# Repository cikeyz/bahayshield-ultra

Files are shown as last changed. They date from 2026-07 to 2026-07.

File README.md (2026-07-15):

# BahayShield ULTRA

<p align="center">
  <strong>Offline flood and typhoon preparedness controller for a tabletop home-safety demo.</strong><br>
  Arduino Mega 2560 Pro · HC-SR04 · BME280 · TRI scoring · low-voltage relay cut
</p>

<p align="center">
  <a href="#overview">Overview</a>
  &nbsp;·&nbsp;
  <a href="#features">Features</a>
  &nbsp;·&nbsp;
  <a href="#gallery">Gallery</a>
  &nbsp;·&nbsp;
  <a href="#quick-start">Quick Start</a>
  &nbsp;·&nbsp;
  <a href="#project-structure">Structure</a>
  &nbsp;·&nbsp;
  <a href="#license">License</a>
</p>

<p align="center">
  
  
  
  
  
  
</p>

## Contents

- [Overview](#overview)
- [Features](#features)
- [System architecture](#system-architecture)
- [Hardware](#hardware)
- [Firmware](#firmware)
- [Gallery](#gallery)
- [Quick Start](#quick-start)
- [Project Structure](#project-structure)
- [Safety](#safety)
- [License](#license)
- [Course Note](#course-note)

## Overview

BahayShield ULTRA is an offline microcontroller system that combines ultrasonic water-level sensing with barometric pressure trend analysis. It computes a Typhoon Risk Index (TRI), stages visual and audible alerts, and can open a low-voltage demo load through a relay when risk stays high long enough.

The demo unit pairs a control enclosure with a house diorama and clear flood tray. It is a tabletop simulation, not a field-installed household electrical product, and it does not switch AC mains.

**Controller:** final build uses an **Arduino Mega 2560 Pro** compact module (ATmega2560, CH340 USB, dual-row 100-mil headers). Early breadboard work may use a full-size Mega 2560 form factor; the MCU and IDE board target stay the same (`Arduino Mega or Mega 2560`).

## Features

| Feature | Description |
|---|---|
| Water level | HC-SR04 over a fixed mast; mapped to dry / ankle / knee / waist / critical |
| Barometric trend | BME280 pressure feeds rolling slope and baseline into TRI |
| Storm profiles | Habagat, Bagyo, and Flash Flood reweight water vs pressure |
| Staged alerts | LED bar, alert LED, buzzer cadence, 20x4 LCD |
| Relay cut | Relay 1 COM-NC on a 5 V demo load; active-LOW coil drive |
| Operator inputs | PCF8574 4x4 keypad, A1 button ladder, serial commands |
| Event log | DS3231 timebase + AT24C32 EEPROM with checksummed records |
| Mechanical stack | KiCad motherboard project, 3D-printed enclosure, HC-SR04 mast |

## System architecture

```mermaid
flowchart LR
  subgraph Inputs
    US[HC-SR04]
    BME[BME280]
    POT[A0 pressure pot]
    BTN[Buttons]
    KEY[Keypad]
  end

  subgraph Controller
    MCU[Mega 2560 Pro<br/>ATmega2560<br/>TRI + FSM]
    RTC[DS3231 RTC]
    PWR[XL4015 5 V rail]
  end

  subgraph Outputs
    LED[TRI LEDs + alert]
    BUZ[Active buzzer]
    REL[Relay 1 COM-NC<br/>5 V load]
    LCD[20x4 I2C LCD]
    LOG[AT24C32 event log]
  end

  US --> MCU
  BME --> MCU
  POT --> MCU
  BTN --> MCU
  KEY --> MCU
  RTC --> MCU
  PWR --> MCU
  MCU --> LED
  MCU --> BUZ
  MCU --> REL
  MCU --> LCD
  MCU --> LOG
```

Editable diagrams: [`docs/diagrams/`](docs/diagrams/).  
Deeper write-up: [`docs/overview.md`](docs/overview.md).

## Hardware

| Block | Part | Role |
|---|---|---|
| MCU | Arduino Mega 2560 Pro (ATmega2560) | Final controller; 5 V on `5V` pin (`VIN` unused) |
| Water | HC-SR04 | Distance over diorama tray |
| Environment | BME280 (I2C, typically `0x76`) | Pressure for TRI; temp/humidity for display only |
| RTC + log | DS3231 + AT24C32 | Timekeeping and event log |
| Display | 20x4 I2C LCD (primary `0x27`) | TRI, profile, water, pressure, state |
| Keypad | 4x4 via PCF8574 (`0x20`) | Profile, mute, cut, ack, page |
| Buttons | 3x tactile on A1 ladder | Yellow cut, Blue view, Green ack |
| Indicators | 5 TRI LEDs + alert LED + buzzer | Staged alert UI |
| Actuator | 2-ch 5 V relay module | Relay 1 demo-load cut; Relay 2 spare |
| Power | USB-C PD source → XL4015 buck → 5.00 V | Fuse + reverse protection on the design |
| Load | 5 V LED strip on Relay 1 COM-NC | Stand-in for a ground-floor branch |
| PCB | KiCad Rev A motherboard | Headers for Mega 2560 Pro and modules |
| Enclosure | Printed base, top panel, BME280 cage, mast | Control unit + sensor geometry |

- Pin map: [`hardware/pinout.md`](hardware/pinout.md)
- Power path: [`hardware/power-tree.md`](hardware/power-tree.md)
- BOM: [`hardware/bom.md`](hardware/bom.md)
- Wiring: [`hardware/wiring-overview.md`](hardware/wiring-overview.md)
- PCB project: [`pcb/`](pcb/)
- Enclosure STLs: [`enclosure/`](enclosure/)

## Firmware

Production sketch: [`firmware/bahayshield-ultra/`](firmware/bahayshield-ultra/)

- Non-blocking `millis()` scheduler
- Fixed-point TRI suited to Mega-class SRAM
- Non-blocking HC-SR04 echo state machine
- Active-LOW relay with confirm window before power-cut latch
- Serial at `115200` baud

Bring-up suite: [`firmware/bring-up/`](firmware/bring-up/) (I2C, LCD, keypad, RTC, BME280, relay, ultrasonic, full breadboard integration).

Libraries for production:

```text
Wire
Adafruit BME280
Adafruit Unified Sensor
Adafruit BusIO
```

LCD and PCF8574 keypad use direct `Wire` access.

## Gallery

| Mega 2560 Pro (front) | Mega 2560 Pro (back) |
|---|---|
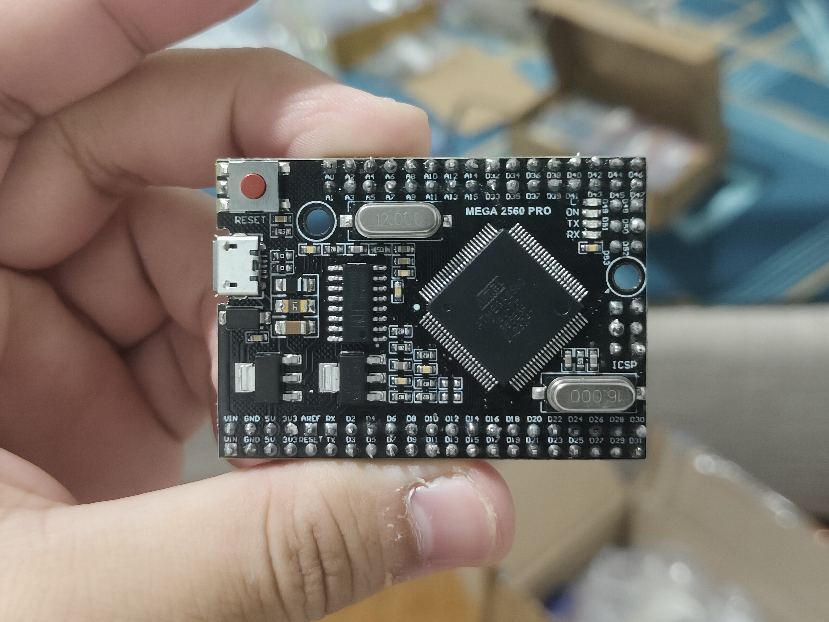
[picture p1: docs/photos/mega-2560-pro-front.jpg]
Mega 2560 Pro front
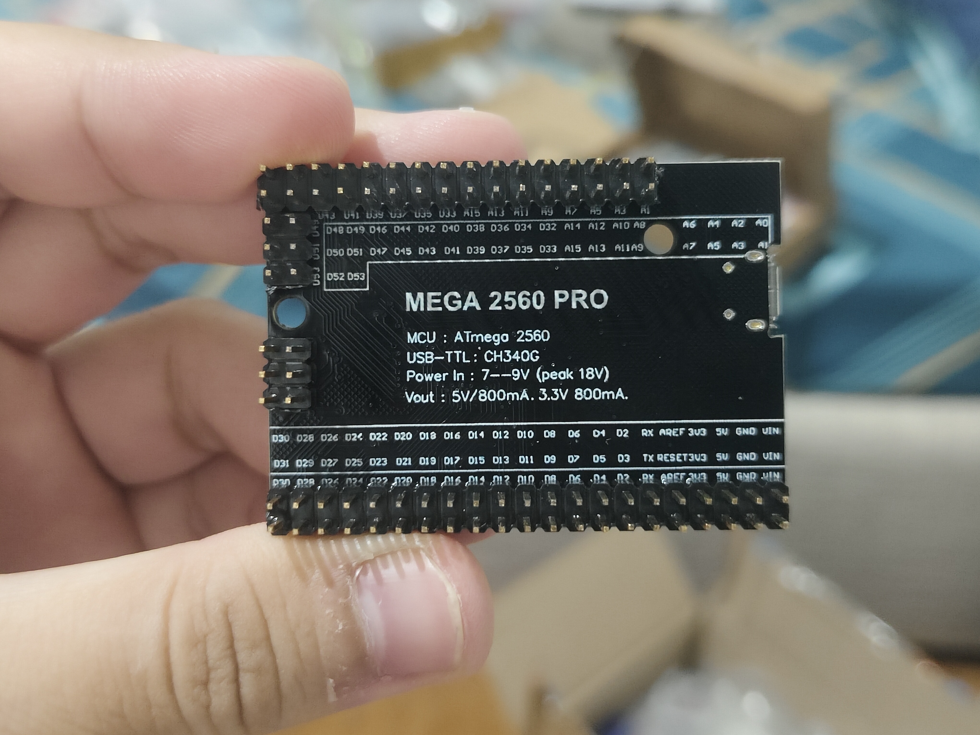
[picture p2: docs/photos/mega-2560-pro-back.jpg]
Mega 2560 Pro back
|  |  |

| BME280 | DS3231 + AT24C32 | XL4015 buck |
|---|---|---|
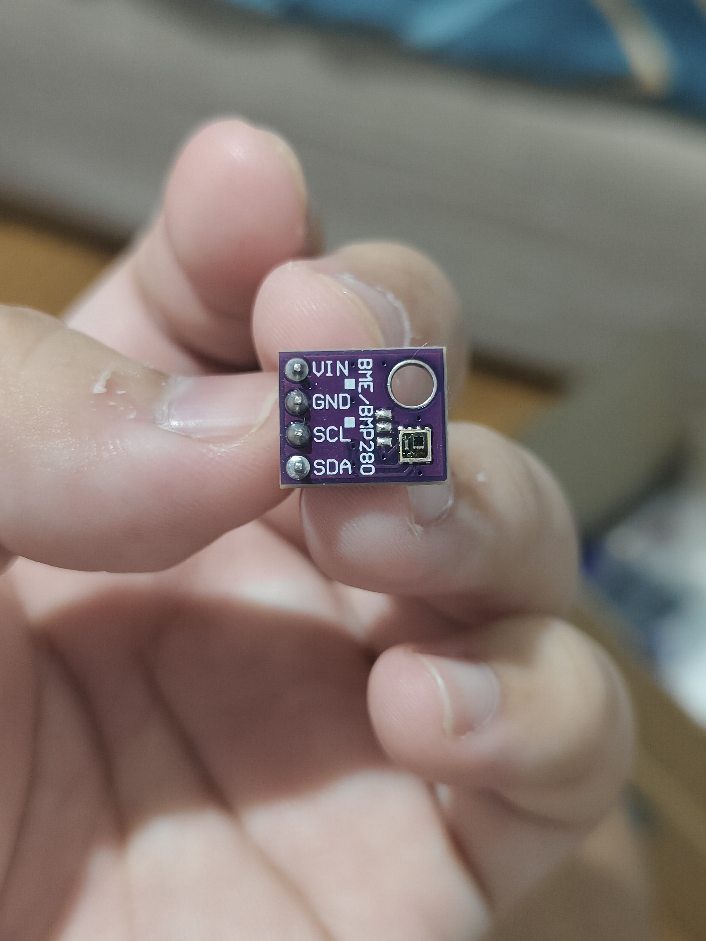
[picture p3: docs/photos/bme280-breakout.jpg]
BME280
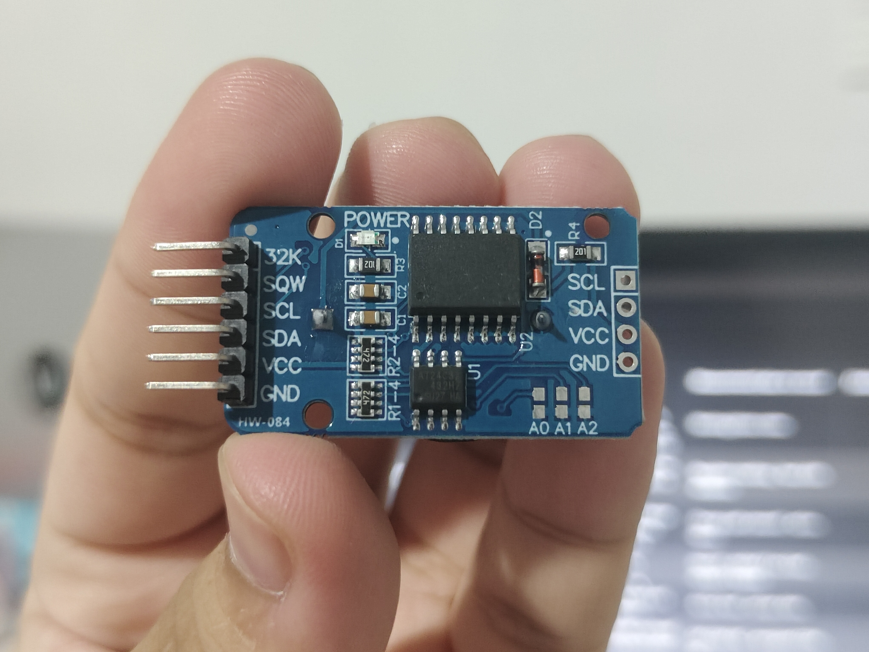
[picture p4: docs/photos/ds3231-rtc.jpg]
DS3231
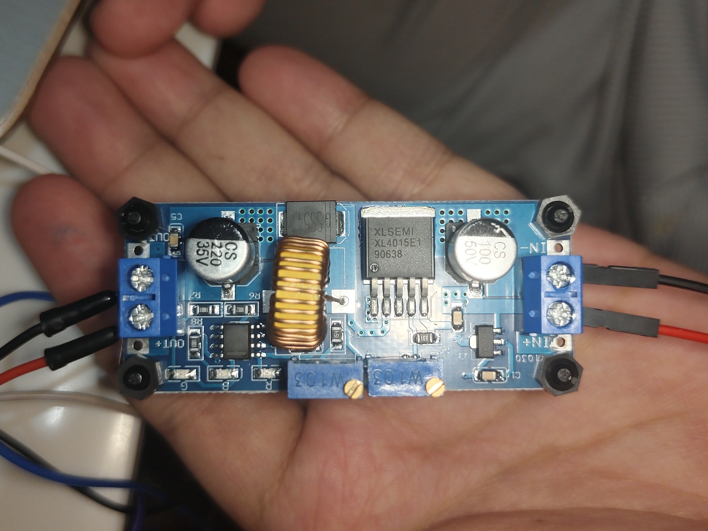
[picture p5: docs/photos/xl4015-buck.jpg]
XL4015
|  |  |  |

| Serial: upload OK | Serial: HC-SR04 |
|---|---|
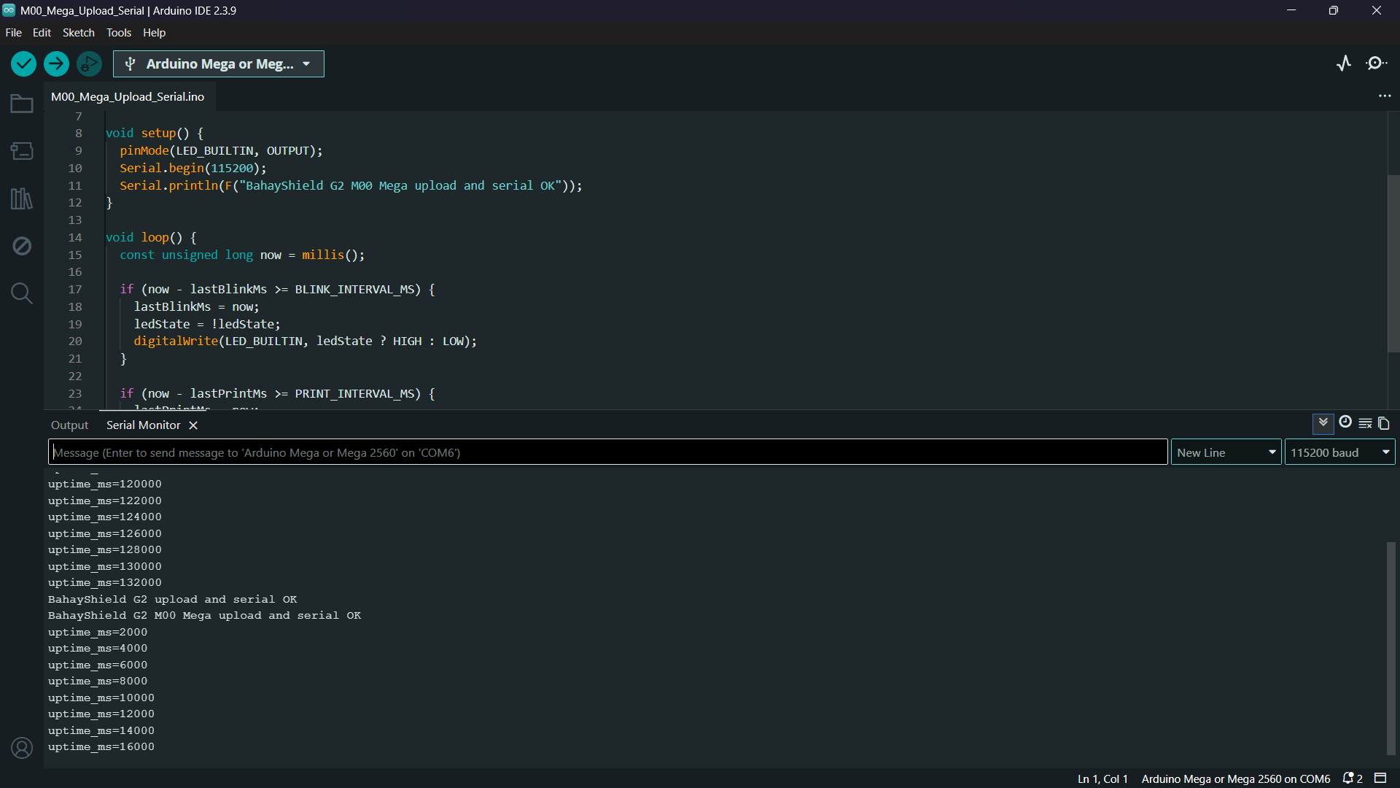
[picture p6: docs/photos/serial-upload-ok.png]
Upload OK
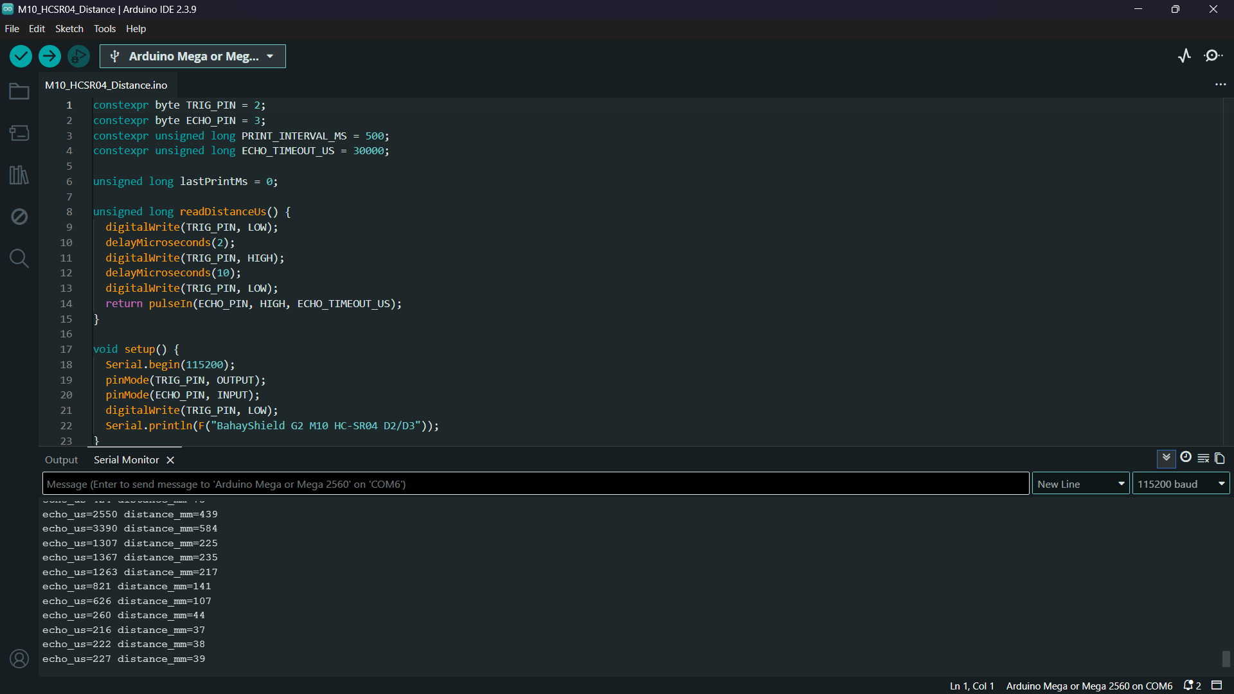
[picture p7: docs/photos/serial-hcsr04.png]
HC-SR04
|  |  |

| Serial: keypad | Serial: LCD I2C |
|---|---|
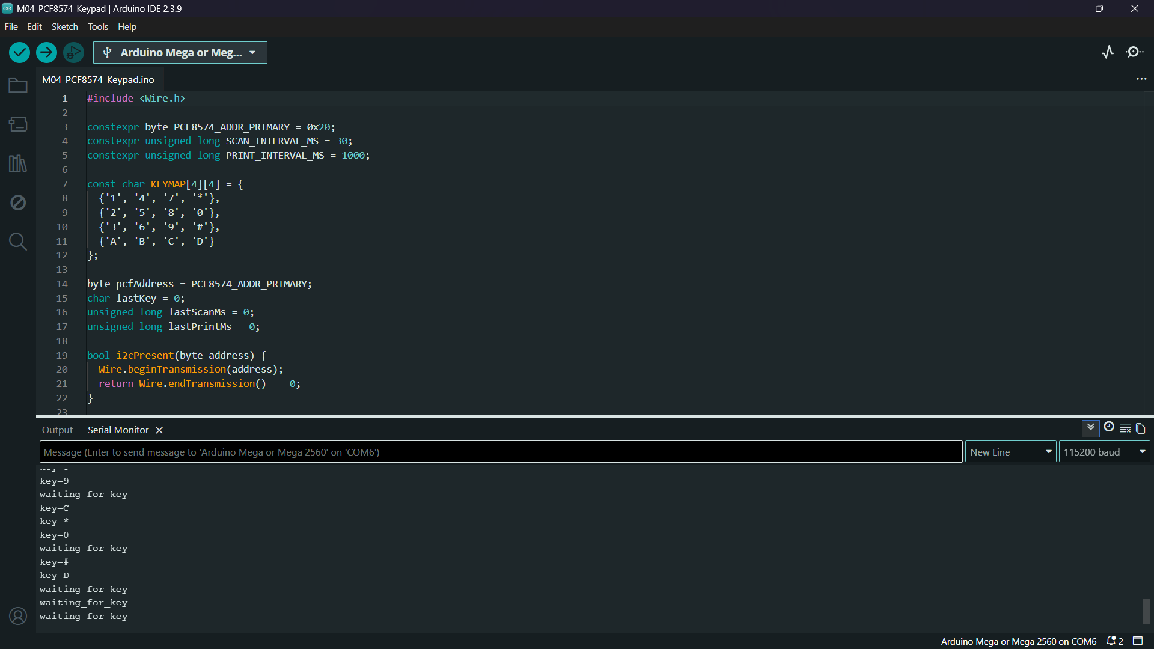
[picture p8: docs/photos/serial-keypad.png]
Keypad
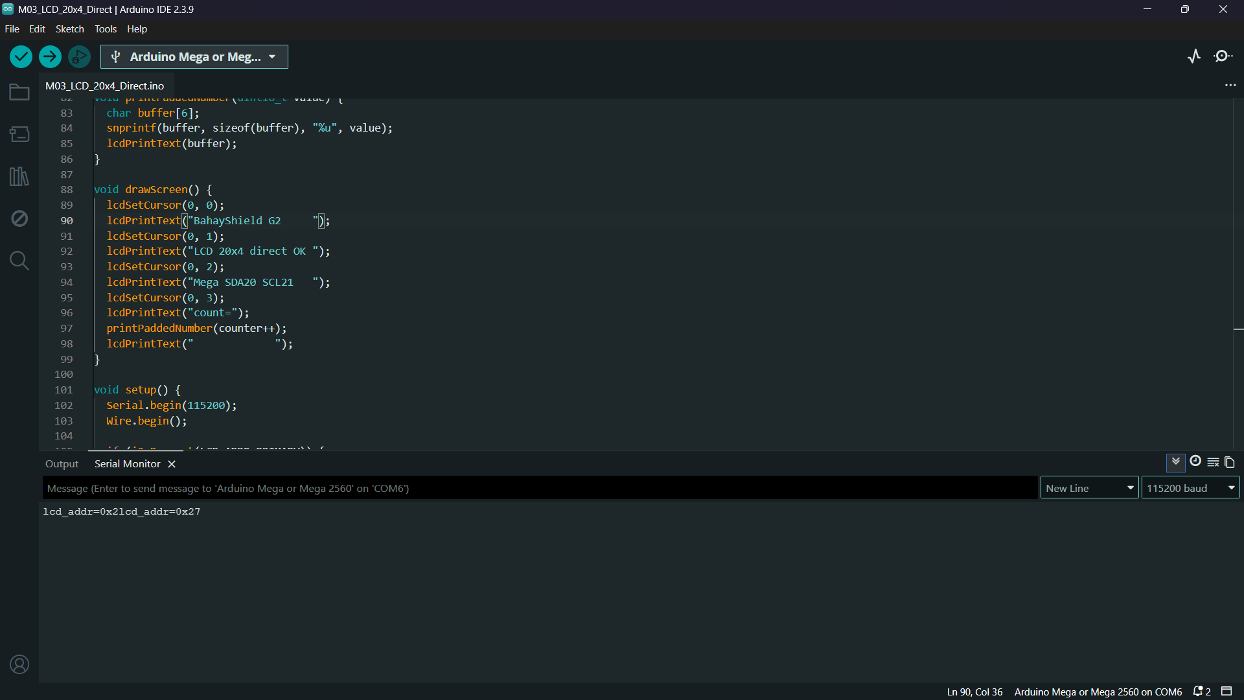
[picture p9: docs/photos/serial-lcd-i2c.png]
LCD
|  |  |

Full set: [`docs/photos/`](docs/photos/).

## Quick Start

```bash
git clone https://github.com/cikeyz/bahayshield-ultra.git
cd bahayshield-ultra
```

1. Install Arduino IDE or Arduino CLI.
2. Select board **Arduino Mega or Mega 2560** (ATmega2560 on the Mega 2560 Pro module).
3. Install Adafruit BME280 and its dependencies.
4. Open `firmware/bahayshield-ultra/bahayshield-ultra.ino`.
5. Upload with the external load disconnected.
6. Open Serial Monitor at `115200`. Confirm I2C devices, LCD, and inactive relay before connecting the LED-strip load path.

| Cmd | Action |
|-----|---|
| `c` | Manual relay cut |
| `a` | Acknowledge / reset when safe |
| `v` | Cycle LCD page |
| `m` | Mute buzzer |
| `1` / `2` / `3` | Habagat / Bagyo / Flash Flood |
| `?` | Help |

Demo script: [`docs/demo-procedure.md`](docs/demo-procedure.md).

## Project Structure

```text
bahayshield-ultra/
├── README.md
├── LICENSE
├── .gitignore
├── firmware/
│   ├── bahayshield-ultra/     # production sketch
│   └── bring-up/              # M00-M16 driver tests
├── hardware/
│   ├── pinout.md
│   ├── power-tree.md
│   ├── bom.md
│   └── wiring-overview.md
├── pcb/
│   ├── README.md
│   ├── rev-a/                 # KiCad Rev A + local libraries
│   └── archive/prototype-1/   # early routing baseline
├── enclosure/
│   ├── README.md
│   ├── scad/
│   └── stl/
└── docs/
    ├── overview.md
    ├── demo-procedure.md
    ├── diagrams/
    └── photos/
```

## Safety

- Relay contacts switch a **5 V demo load** only. No AC, outlets, extension cords, or household branch wiring.
- Humidity and temperature are display/log context. Pressure is the barometric input to TRI and cutoff logic.
- Storm demos can use the A0 potentiometer for a repeatable pressure curve while BME280 still reports real ambient pressure.
- Verify buck output at 5.00 V, relay active level, and COM-NC continuity before a live demo.

## License

MIT. See [LICENSE](LICENSE).

## Course Note

Built for CMPE 311 (Microprocessor Systems), Polytechnic University of the Philippines, Group 4, A.Y. 2025-2026, under Engr. Rufo I. Marasigan Jr., D.Eng, PCpE. Published here as a standalone project.

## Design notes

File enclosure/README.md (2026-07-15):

# Enclosure and mast

Printed parts for the control unit and HC-SR04 mast. Sized around the **Mega 2560 Pro** motherboard stack, internal relay/buck bays, and a top-panel BME280 vent cage open to room air.

## STL set

| File | Role |
|---|---|
| `stl/bahayshield-base-tray.stl` | Base tray |
| `stl/bahayshield-top-panel.stl` | Top panel |
| `stl/bme280-vent-cage.stl` | Room-air sensor cage |
| `stl/hcsr04-faceplate.stl` | Sensor faceplate |
| `stl/hcsr04-mast-base.stl` | Mast base |
| `stl/hcsr04-mast-upright-132mm.stl` | Upright |
| `stl/hcsr04-mast-arm.stl` | Arm |

Editable source: `scad/bahayshield-enclosure.scad` and `scad/generate_enclosure_stl.py`.

## Print notes

| Setting | Suggestion |
|---|---|
| Material | PETG preferred; PLA+ OK for fit checks |
| Layer height | 0.20 mm final |
| Walls | 4+ |
| Infill | ~25% |
| Order | Faceplate and BME280 cage first, then top panel and base, then mast |

Expect holes to need light reaming after print. Keep BME280 exposed to room air.

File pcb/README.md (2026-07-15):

# PCB

## Rev A

Path: [`rev-a/`](rev-a/)

KiCad motherboard for BahayShield ULTRA. It sockets an **Arduino Mega 2560 Pro** on 100-mil headers and brings out I2C modules, relay logic, load path, indicators, and power protection.

```text
pcb/rev-a/BahayShield-ULTRA-RevA-Manual.kicad_pro
```

Local symbol and footprint libraries: `rev-a/libraries/`.

### Status

- Schematic covers the intended nets: MCU headers, I2C, relay inputs, load terminals, protection, bulk caps, TRI LEDs, buzzer drive.
- Before ordering boards, re-run ERC/DRC on your KiCad version, confirm relay header order (`GND IN1 IN2 VCC`) and contact group (`NO COM NC`) against the module you hold, and check keep-outs against the printed enclosure.
- This tree is a design package, not a certified production Gerber drop.

## Prototype-1 (archive)

Path: [`archive/prototype-1/`](archive/prototype-1/)

Early low-voltage routing baseline. Kept for history. Prefer Rev A for current pin and feature set.

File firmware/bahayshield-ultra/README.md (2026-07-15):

# Production firmware

Board: **Arduino Mega 2560 Pro** (ATmega2560, 5 V).

Arduino IDE: **Arduino Mega or Mega 2560**.

## Folder

```text
firmware/bahayshield-ultra/
├── bahayshield-ultra.ino
├── config.h
├── pins.h
├── event_log.h
└── event_log.cpp
```

## Libraries

```text
Wire
Adafruit BME280
Adafruit Unified Sensor
Adafruit BusIO
```

## Serial

Baud: `115200`.

| Command | Action |
|---|---|
| `c` | Manual relay cut |
| `a` | Acknowledge / reset when safe |
| `v` | Cycle LCD page |
| `m` | Mute buzzer |
| `1` / `2` / `3` | Habagat / Bagyo / Flash Flood |
| `e` | Write one event-log smoke record |
| `?` | Help |

Upload with the external load disconnected. Confirm startup prints, LCD, I2C, inactive relay, and 5.00 V rails before connecting the LED-strip load path.

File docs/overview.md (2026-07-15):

# System overview

## Problem

During typhoons and monsoon floods, homes often lose connectivity first. Water and energized ground-floor wiring raise electrocution risk. BahayShield ULTRA is an offline controller that estimates rising risk from water level and pressure trend, stages alerts, and opens a safe low-voltage demo load.

## Architecture

1. **Sense** - HC-SR04 water height, BME280 pressure, A0 pressure simulator for repeatable demos, RTC timebase.
2. **Decide** - Profile-weighted TRI with hysteresis; confirm window before latching power-cut.
3. **Act** - LED bar, buzzer, LCD pages, Relay 1 COM-NC on 5 V load, EEPROM event log.
4. **Operate** - Keypad, panel buttons, serial commands.

Diagrams: [`diagrams/`](diagrams/).

## Alert states

| State | Intent |
|---|---|
| NORMAL | Baseline monitoring |
| WATCH | Elevated TRI |
| WARNING1 | Higher urgency |
| POWER_CUT | Relay latched open after sustained critical conditions |
| EVACUATE | Highest urgency cues |

Threshold constants live in `firmware/bahayshield-ultra/config.h`.

## Storm profiles

| Profile | Bias |
|---|---|
| Habagat | Heavier water weight |
| Bagyo | Heavier pressure-slope weight |
| Flash Flood | Balanced water + slope |

## Controller

Final packaged controller is the compact **Arduino Mega 2560 Pro** (ATmega2560). Full-size Mega 2560 boards are fine for early breadboard work; pin numbers and the IDE board package stay the same.

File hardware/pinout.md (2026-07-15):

# Pin map and I2C map

Final controller: **Arduino Mega 2560 Pro** (ATmega2560, 5 V logic).

Arduino IDE board package: **Arduino Mega or Mega 2560**.

## Digital / analog

| Signal | Pin | Notes |
|---|-----|---|
| HC-SR04 TRIG | D2 | Output |
| HC-SR04 ECHO | D3 | Input |
| Relay 1 (IN1) | D4 | Active LOW |
| Relay 2 (IN2) | D5 | Active LOW; spare / optional |
| TRI LED G1 | D6 | Safe band |
| TRI LED G2 | D7 | |
| TRI LED Y | D8 | |
| TRI LED O | D9 | |
| TRI LED R | D10 | |
| Alert LED | D11 | |
| Buzzer | D12 | Active piezo |
| I2C SDA | D20 | Mega hardware I2C |
| I2C SCL | D21 | Mega hardware I2C |
| Pressure simulator | A0 | Potentiometer; demo storm curve |
| Button ladder | A1 | Yellow / Blue / Green |

Source of truth: `firmware/bahayshield-ultra/pins.h`.

## I2C addresses

| Device | Address | Notes |
|---|---|---|
| 20x4 LCD backpack | `0x27` primary, `0x3F` fallback | Direct `Wire` driver |
| PCF8574 keypad expander | `0x20` | Key map handled in firmware |
| DS3231 RTC | `0x68` | |
| AT24C32 EEPROM | `0x57` | Event log |
| BME280 | `0x76` | Expected chip id `0x60` |

Source of truth: `firmware/bahayshield-ultra/config.h`.

## Relay module header order (HL-52S class)

Logic header: `GND IN1 IN2 VCC`.

Contact group per channel: `NO COM NC`.

- Relay 1: `COM` = load supply in, `NC` = load out (opens when the coil energizes).
- `NO` unused on the minimum demo path.

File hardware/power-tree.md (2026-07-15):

# Power tree

## Path

```text
USB-C PD source (or other protected DC source)
  -> input protection / fuse
  -> buck regulator (XL4015 5 A preferred; LM2596S accepted)
  -> regulated 5.00 V distribution
       -> logic branch: Mega 2560 Pro 5V pin, I2C modules, LCD, LEDs, sensors
       -> actuator branch: relay coils, buzzer, demo load feed into Relay 1 COM
```

## Rules

1. Final board is the **Arduino Mega 2560 Pro**. Feed regulated **5 V into the module `5V` pin**. Leave `VIN` unused.
2. Set and verify the buck output at **5.00 V** before connecting the Mega or peripherals.
3. Do not feed a selectable USB-C PD cable directly into the 5 V logic rail by default.
4. USB is for firmware upload and serial only. Avoid powering logic from USB and external 5 V at the same time unless backfeed isolation is proven.
5. Relay contacts switch a **5 V demo load only**.
6. Share ground intentionally; keep high actuator return current off the sensor/I2C sense path.

## Bench measurements (5 V LED-strip path)

| Point | Approx. reading |
|---|---|
| External supply, no load | ~5.07 V |
| External supply, loaded / switching | ~5.01 V |
| Capacitor node, loaded | ~4.91 V |
| LED-strip current | ~0.39 A |

Breadboard and Dupont drop is expected. Prefer heavier power wire for the final load path.

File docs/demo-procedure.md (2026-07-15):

# Demo procedure

Prerequisites: regulated 5.00 V verified, production firmware on the **Mega 2560 Pro**, demo load disconnected for first boot check.

## Cold start

1. Power the control unit from the buck-regulated 5 V rail.
2. Confirm LCD boots, serial status at 115200 baud, and relay inactive.
3. Confirm I2C devices as available: LCD, PCF8574, DS3231, AT24C32, BME280.
4. Connect the 5 V LED-strip load path only after the above looks healthy.

## Scenario A: rising water

1. Start dry under the HC-SR04 mast.
2. Raise water toward the marked levels (15 / 30 / 55 mm class).
3. Watch TRI LEDs, LCD water reading, and buzzer cadence.
4. At sustained critical risk, confirm Relay 1 opens the COM-NC path (strip off).

## Scenario B: pressure-led storm curve

1. Select Bagyo profile (`2` on serial or keypad).
2. Sweep the A0 potentiometer to simulate falling pressure.
3. Show slope and baseline contribution on the LCD.

## Recovery

1. Return water and pressure inputs to safe levels.
2. Acknowledge (serial `a` / green button / keypad A) when safe conditions hold.
3. Confirm the load path restores when the coil releases.

## Stop rules

- Stop if the 5 V rail collapses, a module overheats, or the relay chatters.
- Never attach AC loads for the demo.

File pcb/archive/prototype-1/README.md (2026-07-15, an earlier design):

# BahayShield ULTRA Prototype-1

Prototype-1 is an early low-voltage KiCad PCB baseline for BahayShield ULTRA. It is an interface and distribution board, not a mains-power controller. Prefer the Rev A project under `pcb/rev-a/` for the current design.

Do not treat this as the current release PCB. It passed the original DRC check, but it no longer satisfies the active implementation requirements by itself.

## Contents

- `bahayshield_ultra_prototype_1.kicad_pro`: KiCad project file.
- `bahayshield_ultra_prototype_1.kicad_pcb`: PCB-authoritative board with footprints, pad nets, board outline, mounting holes, and routed low-voltage nets.
- `bahayshield_ultra_prototype_1.kicad_sch`: schematic stub that points reviewers to the board baseline and pinout register.
- `connector-pinout-register.csv`: connector pin map.
- `docs/design-baseline.md`: design intent and constraints.
- `docs/validation-report.md`: build and DRC summary.
- `manufacturing/release-gate.md`: checks required before fabrication.
- `reports/bom.csv`: grouped BOM.

## Baseline Status

- Date: 2026-05-12
- Components: 21
- Pins assigned: 70
- Named nets: 17
- References: J1A, J1B, J1C, J1D, J1E, J2, J3, J4, J5, J6, J7, J8, J9, J10, J11, J12, J13, R1, R2, C1, C2

## Current Release Blockers

- The accepted implementation requires five TRI bar LEDs plus one separate alert LED on D6 to D11. This baseline exposes only `LED_GREEN`, `LED_YELLOW`, and `LED_RED` through J13.
- The active procurement policy rejects unclear BMP280 voltage variants. This baseline still includes a `+3V3` path, J5 `BMP280_OPTION`, and C2 on `+3V3`; those are unresolved until the final BMP280 module and voltage policy are locked.
- The baseline is a PCB routing proof, not a firmware-validated system. No production BahayShield sketch is tied to this board yet.
- The baseline has no evidence package proving actual purchased connector orientation, module footprint fit, enclosure clearance, or relay-load wiring.

Do not fabricate until the release-gate file is cleared against actual bought modules, connector orientation, enclosure clearances, relay-load wiring, six-indicator output requirements, BMP280 voltage policy, and firmware pin-map proof.

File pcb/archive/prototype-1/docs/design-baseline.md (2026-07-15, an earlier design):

# Prototype-1 Design Baseline

## Intent

This PCB is a low-voltage interface board for the Arduino Mega 2560 Pro based BahayShield ULTRA simulation unit. It breaks out Mega-side control nets to field connectors for the ultrasonic water-level sensor, I2C LCD/RTC/keypad chain, optional BMP280 module, button ladder, pressure simulator, relay inputs, buzzer, and status LEDs.

This file describes the Prototype-1 routing baseline, not the current release design. The active implementation requires six indicator outputs and a locked BMP280 voltage policy before fabrication.

## Electrical Boundaries

- Input power is regulated 5 V only through J11.
- No mains voltage is allowed on this PCB.
- J10 is reserved for the low-voltage demo load path only.
- I2C nets use 4.7 k pullups to 5 V through R1 and R2.
- C1 provides local 5 V decoupling. C2 is tied to the old `+3V3` BMP280 option and must be removed, revised, or formally justified before any release board.
- Power and relay/buzzer traces use wider track widths than logic traces.
- The final board must expose five TRI LED outputs plus one separate alert LED. The three-net `STATUS_LEDS` header in this baseline is incomplete.
- Do not add a default 3.3 V rail only to rescue an unknown BMP280 module. Lock a 5 V I2C-safe module or document a formal level-shifted redesign.

## Connector Policy

Connector pin order is frozen in `connector-pinout-register.csv` for Prototype-1. Physical connector series, wire exit, keying, and shrouding remain release-gate items because the real purchased modules can reverse pin order.

## Layout Policy

- Board size: 135 mm x 95 mm.
- Mounting holes: four M3-compatible holes near corners.
- Copper layers: routed on F.Cu in this baseline.
- Silk labels identify low-voltage status and revision.
- The board file is authoritative for Prototype-1 because the MCP schematic writer corrupts large repeated schematic insertions on this KiCad 10 Windows setup.

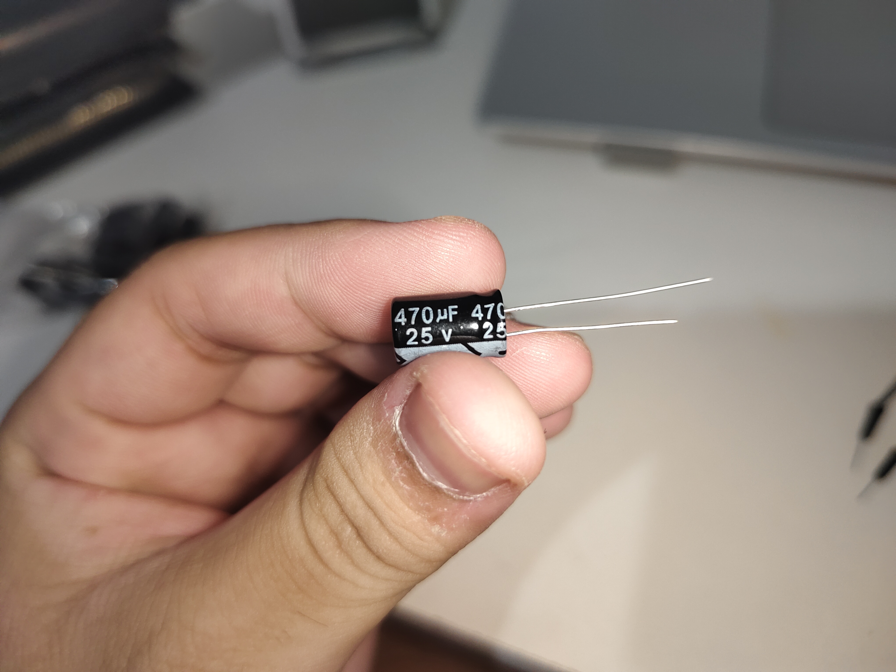
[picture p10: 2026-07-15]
docs/photos/bulk-cap-470uf.jpg

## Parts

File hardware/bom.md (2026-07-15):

# Bill of materials

One simulation unit. No prices or vendor order IDs.

## Electronics

| Item | Spec notes |
|---|---|
| Arduino Mega 2560 Pro | ATmega2560, 5 V, CH340-class USB, 100-mil headers |
| HC-SR04 | Ultrasonic distance |
| BME280 breakout | I2C; pressure required; 5 V-safe module preferred |
| DS3231 + AT24C32 module | RTC + EEPROM |
| 20x4 I2C LCD | Backpack `0x27` common |
| PCF8574 + 4x4 keypad | I2C expander at `0x20` in this build |
| 2-channel 5 V relay module | HL-52S / Songle SRD-05VDC-SL-C class |
| Active piezo buzzer | Enclosure-mounted |
| LEDs + resistors | 5 TRI + 1 alert |
| 3 tactile buttons + ladder resistors | On A1 |
| Potentiometer | A0 pressure simulator |
| Buck regulator | XL4015 5 A preferred |
| Bulk electrolytic | 470 uF class on 5 V rail |
| Fuse holder + fuse | Input protection |
| Schottky reverse protection | e.g. 1N5822 class on input path |
| Headers / JST-XH / KF301 terminals | Interconnects |
| Hookup wire | Signal + ~20 AWG for load path |

## Mechanical / demo

| Item | Spec notes |
|---|---|
| 3D-printed enclosure set | Base tray, top panel, BME280 cage |
| HC-SR04 mast set | Base, upright, arm, faceplate |
| House diorama + clear water tray | Markers at 0 / 15 / 30 / 45 / 55 mm |
| 5 V LED strip | Demo load on Relay 1 COM-NC |

## Out of minimum scope

- Whole-unit battery backup
- 12 V demo-load branch
- Real AC contactors or household wiring
- Outdoor weatherproof deployment

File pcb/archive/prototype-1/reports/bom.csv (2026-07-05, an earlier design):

quantity | references | value | footprint
1 | C2 | 100n I2C_DECOUPLE | Capacitor_THT:C_Disc_D5.0mm_W2.5mm_P2.50mm
1 | C1 | 100n POWER_DECOUPLE | Capacitor_THT:C_Disc_D5.0mm_W2.5mm_P2.50mm
1 | R2 | 4.7k SCL_PULLUP | Resistor_THT:R_Axial_DIN0207_L6.3mm_D2.5mm_P7.62mm_Horizontal
1 | R1 | 4.7k SDA_PULLUP | Resistor_THT:R_Axial_DIN0207_L6.3mm_D2.5mm_P7.62mm_Horizontal
1 | J5 | BMP280_OPTION | Connector_PinHeader_2.54mm:PinHeader_1x04_P2.54mm_Vertical
1 | J7 | BTN_LADDER_A1 | Connector_PinHeader_2.54mm:PinHeader_1x04_P2.54mm_Vertical
1 | J12 | BUZZER_OUT | Connector_PinHeader_2.54mm:PinHeader_1x02_P2.54mm_Vertical
1 | J6 | DIORAMA_USONIC | Connector_PinHeader_2.54mm:PinHeader_1x04_P2.54mm_Vertical
1 | J4 | KEYPAD_I2C | Connector_PinHeader_2.54mm:PinHeader_1x04_P2.54mm_Vertical
1 | J2 | LCD_I2C | Connector_PinHeader_2.54mm:PinHeader_1x04_P2.54mm_Vertical
1 | J10 | LOW_VOLTAGE_DEMO_LOAD | TerminalBlock:TerminalBlock_MaiXu_MX126-5.0-02P_1x02_P5.00mm
1 | J1C | MEGA_ALERTS | Connector_PinHeader_2.54mm:PinHeader_1x04_P2.54mm_Vertical
1 | J1D | MEGA_ANALOG_POWER | Connector_PinHeader_2.54mm:PinHeader_1x04_P2.54mm_Vertical
1 | J1A | MEGA_PWR_I2C | Connector_PinHeader_2.54mm:PinHeader_1x04_P2.54mm_Vertical
1 | J1E | MEGA_SPARE_SERVICE | Connector_PinHeader_2.54mm:PinHeader_1x04_P2.54mm_Vertical
1 | J1B | MEGA_WATER_ACTUATOR | Connector_PinHeader_2.54mm:PinHeader_1x04_P2.54mm_Vertical
1 | J8 | PRESSURE_SIM_A0 | Connector_PinHeader_2.54mm:PinHeader_1x04_P2.54mm_Vertical
1 | J11 | REGULATED_5V_IN | TerminalBlock:TerminalBlock_MaiXu_MX126-5.0-02P_1x02_P5.00mm
1 | J9 | RELAY_IN | Connector_PinHeader_2.54mm:PinHeader_1x04_P2.54mm_Vertical
1 | J3 | RTC_I2C | Connector_PinHeader_2.54mm:PinHeader_1x04_P2.54mm_Vertical
1 | J13 | STATUS_LEDS | Connector_PinHeader_2.54mm:PinHeader_1x04_P2.54mm_Vertical

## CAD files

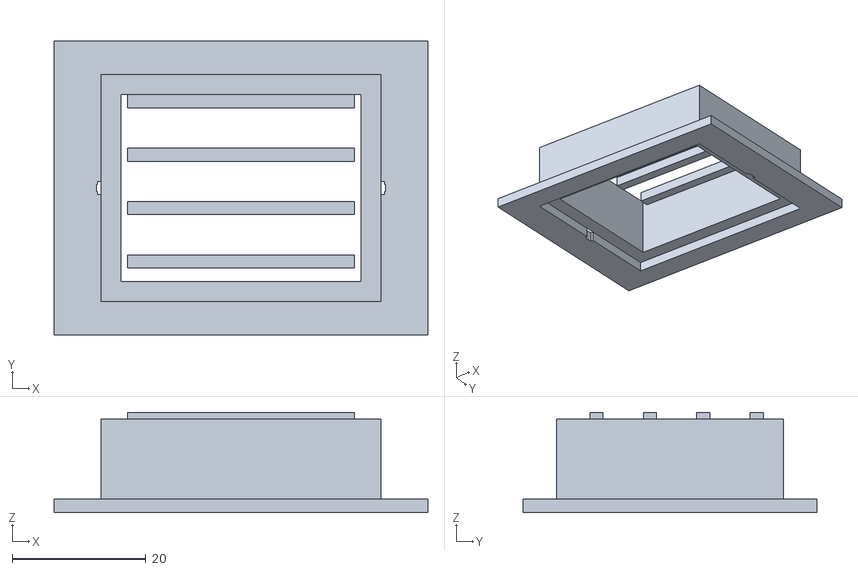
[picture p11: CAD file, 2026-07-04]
enclosure/stl/bme280-vent-cage.stl
56.0 x 44.0 x 15.0

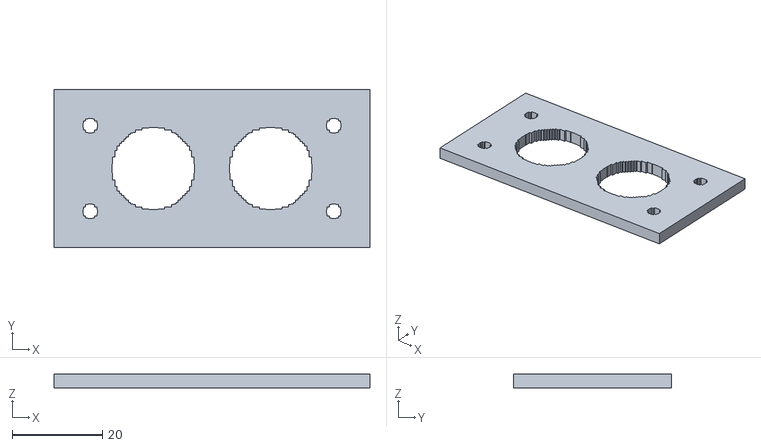
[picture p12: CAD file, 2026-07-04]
enclosure/stl/hcsr04-faceplate.stl
70.0 x 35.0 x 3.00

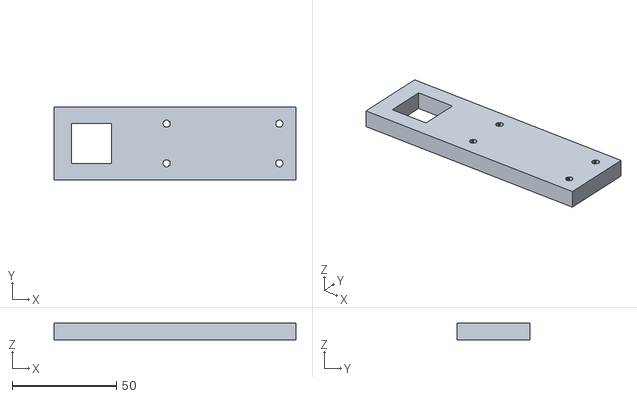
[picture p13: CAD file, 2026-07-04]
enclosure/stl/hcsr04-mast-arm.stl
116.0 x 35.0 x 8.00

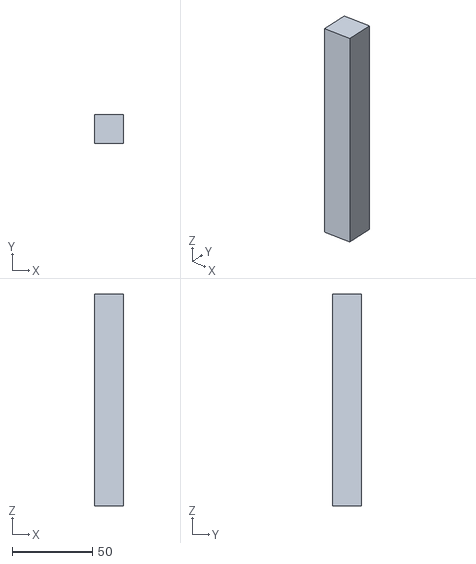
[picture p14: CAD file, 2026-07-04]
enclosure/stl/hcsr04-mast-upright-132mm.stl
18.0 x 18.0 x 132.0

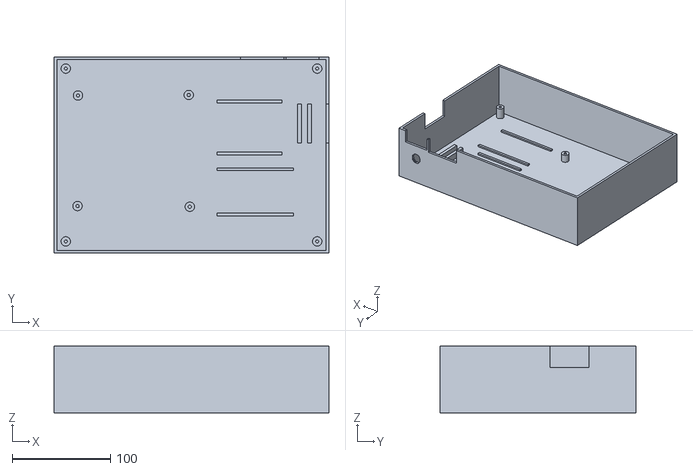
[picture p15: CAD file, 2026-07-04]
enclosure/stl/bahayshield-base-tray.stl
280.0 x 200.0 x 68.0

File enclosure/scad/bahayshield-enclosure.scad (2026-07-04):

$fn = 64;

panel_w = 280;
panel_d = 200;
panel_t = 3.2;
base_h = 68;
wall = 3;
floor_t = 3;

pcb_x = 18;
pcb_y = 42;
pcb_size = 125;
pcb_standoff_h = 10;
pcb_holes = [[6.0, 6.0], [120.3, 5.3], [6.4, 118.6], [119.2, 119.1]];
dc_jack_x = 253;
dc_jack_z = 34;
dc_jack_d = 12.4;

module hole(d, h = 20) {
    cylinder(d = d, h = h, center = true);
}

module back_wall_segment(x0, w, h) {
    difference() {
        translate([x0, panel_d - wall, 0]) cube([w, wall, h]);
        if (dc_jack_x >= x0 + dc_jack_d / 2 && dc_jack_x <= x0 + w - dc_jack_d / 2 && dc_jack_z >= dc_jack_d / 2 && dc_jack_z <= h - dc_jack_d / 2) {
            translate([dc_jack_x, panel_d - wall / 2, dc_jack_z]) rotate([90, 0, 0]) hole(dc_jack_d, wall + 2);
        }
    }
}

module base_tray() {
    cube([panel_w, panel_d, floor_t]);
    cube([panel_w, wall, base_h]);
    cube([wall, panel_d, base_h]);

    // Back wall with service notches and 12.4 mm DC barrel jack opening.
    back_wall_segment(0, 190, base_h);
    back_wall_segment(190, 44, base_h - 18);
    back_wall_segment(234, 2, base_h);
    back_wall_segment(236, 34, base_h - 16);
    back_wall_segment(270, 10, base_h);

    // Right wall with low-voltage load-wire exit.
    translate([panel_w - wall, 0, 0]) cube([wall, 112, base_h]);
    translate([panel_w - wall, 112, 0]) cube([wall, 40, base_h - 22]);
    translate([panel_w - wall, 152, 0]) cube([wall, panel_d - 152, base_h]);

    for (x = [12, panel_w - 12]) {
        for (y = [12, panel_d - 12]) {
            translate([x, y, floor_t]) difference() {
                cylinder(d = 9.6, h = 14);
                translate([0, 0, -1]) cylinder(d = 3.2, h = 16);
            }
        }
    }

    for (p = pcb_holes) {
        translate([pcb_x + p[0], pcb_y + p[1], floor_t]) difference() {
            cylinder(d = 9.6, h = pcb_standoff_h);
            translate([0, 0, -1]) cylinder(d = 3.4, h = pcb_standoff_h + 2);
        }
    }

    // Internal rails mark module zones and give cable-tie anchor points.
    translate([166, 38, floor_t]) cube([78, 3, 2]);
    translate([166, 84, floor_t]) cube([78, 3, 2]);
    translate([166, 100, floor_t]) cube([66, 3, 2]);
    translate([166, 153, floor_t]) cube([66, 3, 2]);
    translate([248, 112, floor_t]) cube([4, 40, 8]);
    translate([258, 112, floor_t]) cube([4, 40, 8]);
}

module top_panel() {
    difference() {
        cube([panel_w, panel_d, panel_t]);

        // LCD, keypad, BME280 vent/recess, rocker switch, and service notch.
        translate([25, 27, -1]) cube([79, 28, panel_t + 2]);
        translate([170, 96, -1]) cube([24, 8, panel_t + 2]);
        translate([238, 24, -1]) cube([30, 24, panel_t + 2]);
        translate([239, 58, -1]) cube([24, 4, panel_t + 2]);
        translate([239, 66, -1]) cube([24, 4, panel_t + 2]);
        translate([236, 143, -1]) cube([15, 10, panel_t + 2]);
        translate([242, 178, -1]) cube([34, 12, panel_t + 2]);

        for (x = [19.5, 109.3]) {
            for (y = [20.5, 62]) {
                translate([x, y, panel_t / 2]) hole(3.4, panel_t + 2);
            }
        }

        for (x = [28, 44, 60, 76, 92, 112, 132]) {
            translate([x, 116, panel_t / 2]) hole(7.6, panel_t + 2);
        }

        for (x = [30, 62, 94]) {
            translate([x, 152, panel_t / 2]) hole(12.4, panel_t + 2);
        }

        translate([132, 152, panel_t / 2]) hole(7.4, panel_t + 2);

        for (dx = [-6, 0, 6]) {
            for (dy = [-6, 0, 6]) {
                translate([186 + dx, 152 + dy, panel_t / 2]) hole(2.6, panel_t + 2);
            }
        }

        for (x = [232, 272]) {
            translate([x, 36, panel_t / 2]) hole(3.2, panel_t + 2);
        }

        for (x = [12, panel_w - 12]) {
            for (y = [12, panel_d - 12]) {
                translate([x, y, panel_t / 2]) hole(3.4, panel_t + 2);
            }
        }
    }
}

module bme280_vent_cage() {
    difference() {
        cube([56, 44, 2]);
        translate([7, 5, -1]) cube([42, 34, 4]);
        translate([8, 22, 1]) hole(3.2, 4);
        translate([48, 22, 1]) hole(3.2, 4);
    }
    translate([7, 5, 2]) cube([3, 34, 12]);
    translate([46, 5, 2]) cube([3, 34, 12]);
    translate([7, 5, 2]) cube([42, 3, 12]);
    translate([7, 36, 2]) cube([42, 3, 12]);
    for (y = [10, 18, 26, 34]) {
        translate([11, y, 13]) cube([34, 2, 2]);
    }
}

module hcsr04_faceplate() {
    difference() {
        cube([70, 35, 3]);
        translate([22, 17.5, 1.5]) hole(18.2, 5);
        translate([48, 17.5, 1.5]) hole(18.2, 5);
        translate([8, 8, 1.5]) hole(3.2, 5);
        translate([62, 8, 1.5]) hole(3.2, 5);
        translate([8, 27, 1.5]) hole(3.2, 5);
        translate([62, 27, 1.5]) hole(3.2, 5);
    }
}

module hcsr04_mast_base() {
    difference() {
        cube([90, 80, 8]);
        translate([35.5, 30.5, -1]) cube([19, 19, 10]);
        for (x = [10, 80]) {
            for (y = [10, 70]) {
                translate([x, y, 4]) hole(3.4, 10);
            }
        }
    }
}

module hcsr04_mast_upright() {
    cube([18, 18, 132]);
}

module hcsr04_mast_arm() {
    difference() {
        cube([116, 35, 8]);
        translate([8.5, 8, -1]) cube([19, 19, 10]);
        for (x = [54, 108]) {
            for (y = [8, 27]) {
                translate([x, y, 4]) hole(3.4, 10);
            }
        }
    }
}

base_tray();
translate([0, panel_d + 20, 0]) top_panel();
translate([0, panel_d + 240, 0]) bme280_vent_cage();
translate([80, panel_d + 240, 0]) hcsr04_faceplate();
translate([0, panel_d + 310, 0]) hcsr04_mast_base();
translate([110, panel_d + 310, 0]) hcsr04_mast_upright();
translate([150, panel_d + 310, 0]) hcsr04_mast_arm();

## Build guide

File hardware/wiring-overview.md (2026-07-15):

# Wiring overview

## MCU form factor

Final harness and PCB assume the **Arduino Mega 2560 Pro** module on 100-mil headers. Early tests may use a full-size Mega 2560 board; pin numbers in software stay the same.

## I2C bus

Shared bus on D20/D21:

- LCD
- PCF8574 keypad
- DS3231 + AT24C32
- BME280 (vented to room air; not sealed in a closed box and not inside the wet diorama)

## Relay load path (minimum demo)

```text
External 5 V load supply +  --->  Relay1 COM
Relay1 NC                   --->  LED strip +
LED strip -                 --->  External 5 V load supply -

Relay logic VCC / GND / IN1 from Mega-side 5 V / GND / D4
```

- Active level: **LOW** energizes the coil.
- Safe idle: inputs held inactive so reset/boot does not cut the load by accident.
- Never put mains on the contact terminals.

## Ultrasonic mast geometry

- Sensor face height: 120 mm above inside tray floor (design target)
- Water markers: 0 / 15 / 30 / 45 / 55 mm from tray floor
- Keep a clear measurement well under the sensor; aim vertical

Water mapping constants: `firmware/bahayshield-ultra/config.h`.

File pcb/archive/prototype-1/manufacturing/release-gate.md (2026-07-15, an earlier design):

# Prototype-1 Release Gate

Do not export Gerbers until each item is signed off.

- Confirm whether this Prototype-1 board is being retired, revised, or used only as a routing reference. It is not the active release PCB until all blockers below are closed.
- Confirm Arduino Mega 2560 Pro header spacing, USB clearance, reset access, and orientation.
- Confirm J11 regulated 5 V input connector footprint and polarity.
- Confirm J10 demo-load connector footprint, load current, and isolation from any mains wiring.
- Confirm relay module input pin order and active level.
- Confirm ultrasonic, LCD, RTC, keypad, BMP280, buzzer, LED, pressure simulator, and button-ladder module pin order.
- Block release if the board does not expose six indicator outputs: five TRI bar LEDs plus one separate alert LED matching firmware pins D6 to D11.
- Block release if the BMP280 path still assumes `+3V3` without a locked module variant, documented regulator or level-shift design, and matching firmware and schematic notes.
- Block release if `+3V3`, J5 `BMP280_OPTION`, or C2 remains on the board only because of the old baseline rather than a documented final electrical decision.
- Block release if the connector pinout register does not match the production firmware pin map.
- Block release if the production firmware sketch has not compiled for Arduino Mega 2560 with the same pin map.
- Block release if the A1 button ladder resistor values and measured ADC windows are not recorded.
- Confirm enclosure standoffs against four M3 mounting holes.
- Run KiCad DRC after final footprint substitutions.
- Capture board screenshot, DRC report, BOM, and continuity test photos before defense.

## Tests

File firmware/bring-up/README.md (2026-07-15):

# Bring-up sketches

Single-purpose tests used while integrating the **Mega 2560 Pro** and modules. Upload one sketch at a time. Board target: **Arduino Mega or Mega 2560**.

| Sketch | Purpose |
|---|---|
| M00 | Upload + serial smoke |
| M02 | I2C scanner |
| M03 | 20x4 LCD direct |
| M04 | PCF8574 keypad |
| M05 | DS3231 + AT24C32 |
| M07 | A0 pressure pot |
| M08 | A1 button ladder |
| M09 | TRI LEDs + buzzer |
| M10 | HC-SR04 distance |
| M11 | BME280 read |
| M12 | Relay active-level |
| M13 | Relay COM-NC demo load |
| M14 | Full breadboard integration |
| M15 | Mast geometry calibration |
| M16 | Water-level marker response |

M11 and M14 need Adafruit BME280 (+ dependencies). Most others use Arduino core + `Wire` only.

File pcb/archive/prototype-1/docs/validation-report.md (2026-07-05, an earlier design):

# Prototype-1 Validation Report

## Build Result

- Board generated: bahayshield_ultra_prototype_1.kicad_pcb
- Components placed: 21
- Routed connections created: 49
- BOM written: reports/bom.csv
- Pinout written: connector-pinout-register.csv

## KiCad CLI DRC

- Ran: True
- Success exit: True
- Return code: 0
- Summary: Found 0 violations Found 0 unconnected items Saved DRC Report to D:\OneDrive\Documents\University\3rd-Year\2nd-Sem-Agent\MICRO\KiCAD\Prototype-1\reports\drc-report.json

See `reports/drc-report.json` for machine-readable results when KiCad CLI completes DRC.

## Known Limits

- This is a Prototype-1 board baseline, not a fabrication release.
- Physical connector footprints must be checked against bought modules before Gerber export.
- Relay/load isolation must be reviewed with the final relay module.
- The schematic is a stub because the MCP schematic inserter failed after repeated symbol additions. The board and pinout register are the source of truth for this baseline.

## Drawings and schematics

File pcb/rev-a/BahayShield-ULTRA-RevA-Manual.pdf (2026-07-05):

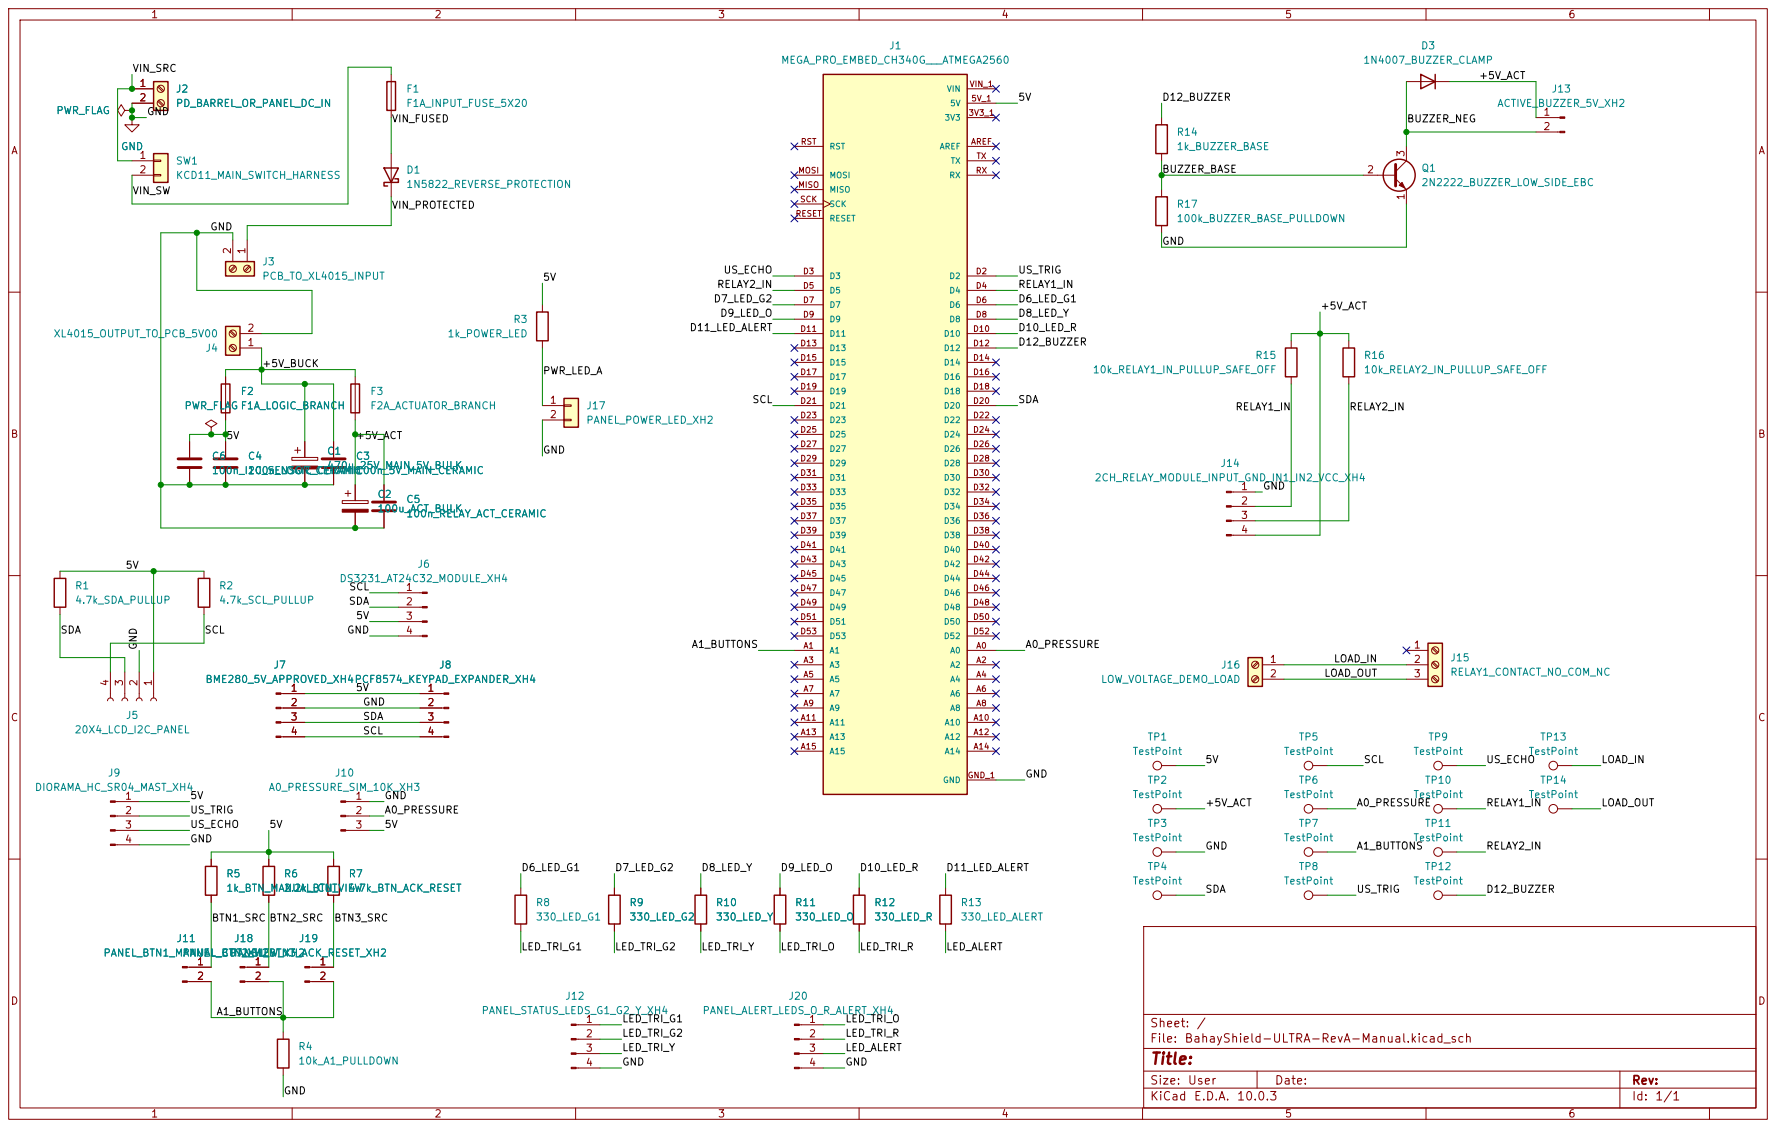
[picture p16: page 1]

Sheet: /
File: BahayShield-ULTRA-RevA-Manual.kicad_sch
Title:

Size: User | Rev:
KiCad E.D.A. 10.0.3 | Id: 1/1

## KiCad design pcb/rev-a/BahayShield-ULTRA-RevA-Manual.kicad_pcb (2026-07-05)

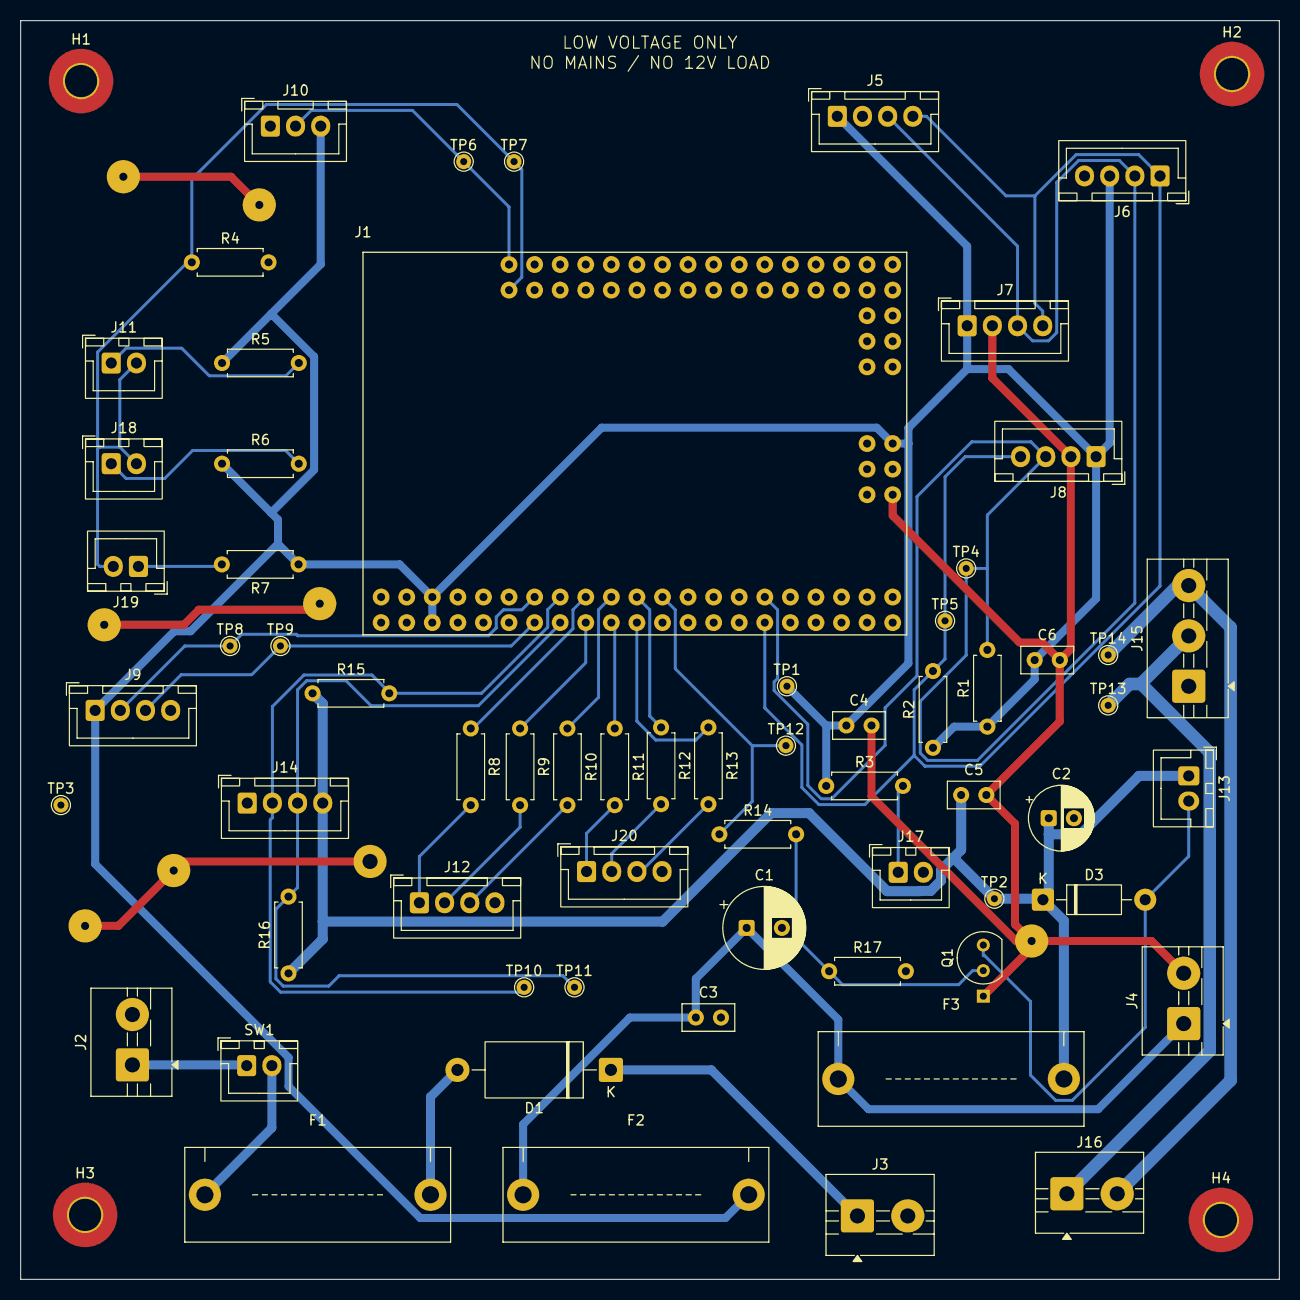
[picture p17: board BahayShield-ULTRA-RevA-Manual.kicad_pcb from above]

Board: 2 copper layers, 125.0 x 125.0 mm, 68 parts (0 on the bottom side), 37 nets.

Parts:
C1: 470u_25V_MAIN_5V_BULK; CP_Radial_D8.0mm_P3.50mm
C2: 100u_ACT_BULK; CP_Radial_D6.3mm_P2.50mm
C3: 100n_5V_MAIN_CERAMIC; C_Disc_D5.0mm_W2.5mm_P2.50mm
C4: 100n_LOGIC_CERAMIC; C_Disc_D5.0mm_W2.5mm_P2.50mm
C5: 100n_RELAY_ACT_CERAMIC; C_Disc_D5.0mm_W2.5mm_P2.50mm
C6: 100n_I2C_SENSOR_CERAMIC; C_Disc_D5.0mm_W2.5mm_P2.50mm
D1: 1N5822_REVERSE_PROTECTION; D_DO-27_P15.24mm_Horizontal
D3: 1N4007_BUZZER_CLAMP; D_DO-41_SOD81_P10.16mm_Horizontal
F1: F1A_INPUT_FUSE_5X20; Fuseholder_5x20mm_TwoProng_P22.40mm_Drill1.70mm
F2: F1A_LOGIC_BRANCH; Fuseholder_5x20mm_TwoProng_P22.40mm_Drill1.70mm
F3: F2A_ACTUATOR_BRANCH; Fuseholder_5x20mm_TwoProng_P22.40mm_Drill1.70mm
H1, H2, H3, H4: MountingHole_3.2mm_M3_Pad_TopBottom
J1: MEGA_PRO_EMBED_CH340G___ATMEGA2560; MODULE_MEGA_PRO_EMBED_CH340G___ATMEGA2560
J2: PD_BARREL_OR_PANEL_DC_IN; KF301-5.0-02P_1x02_P5.00mm_Drill1.50mm_Pad3.30mm
J3: PCB_TO_XL4015_INPUT; KF301-5.0-02P_1x02_P5.00mm_Drill1.50mm_Pad3.30mm
J4: XL4015_OUTPUT_TO_PCB_5V00; KF301-5.0-02P_1x02_P5.00mm_Drill1.50mm_Pad3.30mm
J5: 20X4_LCD_I2C_PANEL; JST_XH_B4B-XH-A_1x04_P2.50mm_Vertical_Drill1.10mm
J6: DS3231_AT24C32_MODULE_XH4; JST_XH_B4B-XH-A_1x04_P2.50mm_Vertical_Drill1.10mm
J7: BME280_5V_APPROVED_XH4; JST_XH_B4B-XH-A_1x04_P2.50mm_Vertical_Drill1.10mm
J8: PCF8574_KEYPAD_EXPANDER_XH4; JST_XH_B4B-XH-A_1x04_P2.50mm_Vertical_Drill1.10mm
J9: DIORAMA_HC_SR04_MAST_XH4; JST_XH_B4B-XH-A_1x04_P2.50mm_Vertical_Drill1.10mm
J10: A0_PRESSURE_SIM_10K_XH3; JST_XH_B3B-XH-A_1x03_P2.50mm_Vertical_Drill1.10mm
J11: PANEL_BTN1_MANUAL_CUT_XH2; JST_XH_B2B-XH-A_1x02_P2.50mm_Vertical_Drill1.10mm
J12: PANEL_STATUS_LEDS_G1_G2_Y_XH4; JST_XH_B4B-XH-A_1x04_P2.50mm_Vertical_Drill1.10mm
J13: ACTIVE_BUZZER_5V_XH2; JST_XH_B2B-XH-A_1x02_P2.50mm_Vertical_Drill1.10mm
J14: 2CH_RELAY_MODULE_INPUT_GND_IN1_IN2_VCC_XH4; JST_XH_B4B-XH-A_1x04_P2.50mm_Vertical_Drill1.10mm
J15: RELAY1_CONTACT_NO_COM_NC; KF301-5.0-03P_1x03_P5.00mm_Drill1.50mm_Pad3.30mm
J16: LOW_VOLTAGE_DEMO_LOAD; KF301-5.0-02P_1x02_P5.00mm_Drill1.50mm_Pad3.30mm
J17: PANEL_POWER_LED_XH2; JST_XH_B2B-XH-A_1x02_P2.50mm_Vertical_Drill1.10mm
J18: PANEL_BTN2_VIEW_XH2; JST_XH_B2B-XH-A_1x02_P2.50mm_Vertical_Drill1.10mm
J19: PANEL_BTN3_ACK_RESET_XH2; JST_XH_B2B-XH-A_1x02_P2.50mm_Vertical_Drill1.10mm
J20: PANEL_ALERT_LEDS_O_R_ALERT_XH4; JST_XH_B4B-XH-A_1x04_P2.50mm_Vertical_Drill1.10mm
Q1: 2N2222_BUZZER_LOW_SIDE_EBC; TO-92_Inline
R1: 4.7k_SDA_PULLUP; R_Axial_DIN0207_L6.3mm_D2.5mm_P7.62mm_Horizontal
R2: 4.7k_SCL_PULLUP; R_Axial_DIN0207_L6.3mm_D2.5mm_P7.62mm_Horizontal
R3: 1k_POWER_LED; R_Axial_DIN0207_L6.3mm_D2.5mm_P7.62mm_Horizontal
R4: 10k_A1_PULLDOWN; R_Axial_DIN0207_L6.3mm_D2.5mm_P7.62mm_Horizontal
R5: 1k_BTN_MANUAL_CUT; R_Axial_DIN0207_L6.3mm_D2.5mm_P7.62mm_Horizontal
R6: 2.2k_BTN_VIEW; R_Axial_DIN0207_L6.3mm_D2.5mm_P7.62mm_Horizontal
R7: 4.7k_BTN_ACK_RESET; R_Axial_DIN0207_L6.3mm_D2.5mm_P7.62mm_Horizontal
R8: 330_LED_G1; R_Axial_DIN0207_L6.3mm_D2.5mm_P7.62mm_Horizontal
R9: 330_LED_G2; R_Axial_DIN0207_L6.3mm_D2.5mm_P7.62mm_Horizontal
R10: 330_LED_Y; R_Axial_DIN0207_L6.3mm_D2.5mm_P7.62mm_Horizontal
R11: 330_LED_O; R_Axial_DIN0207_L6.3mm_D2.5mm_P7.62mm_Horizontal
R12: 330_LED_R; R_Axial_DIN0207_L6.3mm_D2.5mm_P7.62mm_Horizontal
R13: 330_LED_ALERT; R_Axial_DIN0207_L6.3mm_D2.5mm_P7.62mm_Horizontal
R14: 1k_BUZZER_BASE; R_Axial_DIN0207_L6.3mm_D2.5mm_P7.62mm_Horizontal
R15: 10k_RELAY1_IN_PULLUP_SAFE_OFF; R_Axial_DIN0207_L6.3mm_D2.5mm_P7.62mm_Horizontal
R16: 10k_RELAY2_IN_PULLUP_SAFE_OFF; R_Axial_DIN0207_L6.3mm_D2.5mm_P7.62mm_Horizontal
R17: 100k_BUZZER_BASE_PULLDOWN; R_Axial_DIN0207_L6.3mm_D2.5mm_P7.62mm_Horizontal
SW1: KCD11_MAIN_SWITCH_HARNESS; JST_XH_B2B-XH-A_1x02_P2.50mm_Vertical_Drill1.10mm
TP1, TP2, TP3, TP4, TP5, TP6, TP7, TP8, TP9, TP10, TP11, TP12, TP13, TP14: TestPoint; TestPoint_THTPad_D1.5mm_Drill0.7mm

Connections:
5V: C4.1, C6.1, F2.2, J1.5V_1 (5V), J1.5V_2 (5V), J1.5V_3 (5V), J5.1, J6.3, J7.1, J8.1, J9.1, J10.3, R1.1, R2.1, R3.1, R5.1, R6.1, R7.1, TP1.1 (1_1)
/+5V_ACT: C2.1, C5.1, D3.1 (K), F3.2, J13.1, J14.4, R15.1, R16.1, TP2.1 (1_1)
/+5V_BUCK: C1.1, C3.1, F2.1, F3.1, J4.1
/A0_PRESSURE: J1.A0, J10.2, TP6.1 (1_1)
/A1_BUTTONS: J1.A1, J11.2, J18.2, J19.2, R4.1, TP7.1 (1_1)
/BTN1_SRC: J11.1, R5.2
/BTN2_SRC: J18.1, R6.2
/BTN3_SRC: J19.1, R7.2
/BUZZER_BASE: Q1.2 (B), R14.2, R17.1
/BUZZER_NEG: D3.2 (A), J13.2, Q1.3 (C)
/D6_LED_G1: J1.D6, R8.1
/D7_LED_G2: J1.D7, R9.1
/D8_LED_Y: J1.D8, R10.1
/D9_LED_O: J1.D9, R11.1
/D10_LED_R: J1.D10, R12.1
/D11_LED_ALERT: J1.D11, R13.1
/D12_BUZZER: J1.D12, R14.1, TP12.1 (1_1)
/LED_ALERT: J20.3, R13.2
/LED_TRI_G1: J12.1, R8.2
/LED_TRI_G2: J12.2, R9.2
/LED_TRI_O: J20.1, R11.2
/LED_TRI_R: J20.2, R12.2
/LED_TRI_Y: J12.3, R10.2
/LOAD_IN: J15.2, J16.1, TP13.1 (1_1)
/LOAD_OUT: J15.3, J16.2, TP14.1 (1_1)
/PWR_LED_A: J17.1, R3.2
/RELAY1_IN: J1.D4, J14.2, R15.2, TP10.1 (1_1)
/RELAY2_IN: J1.D5, J14.3, R16.2, TP11.1 (1_1)
/SCL: J1.D21, J5.4, J6.1, J7.4, J8.4, R2.2, TP5.1 (1_1)
/SDA: J1.D20, J5.3, J6.2, J7.3, J8.3, R1.2, TP4.1 (1_1)
/US_ECHO: J1.D3, J9.3, TP9.1 (1_1)
/US_TRIG: J1.D2, J9.2, TP8.1 (1_1)
/VIN_FUSED: D1.2 (A), F1.2
/VIN_PROTECTED: D1.1 (K), J3.1
/VIN_SRC: J2.1, SW1.1
/VIN_SW: F1.1, SW1.2
GND: C1.2, C2.2, C3.2, C4.2, C5.2, C6.2, J1.GND_1 (GND), J1.GND_2 (GND), J1.GND_3 (GND), J2.2, J3.2, J4.2, J5.2, J6.4, J7.2, J8.2, J9.4, J10.1, J12.4, J14.1, J17.2, J20.4, Q1.1 (E), R4.2, R17.2, TP3.1 (1_1)

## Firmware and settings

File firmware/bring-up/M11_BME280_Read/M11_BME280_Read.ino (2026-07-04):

#include <Wire.h>
#include <Adafruit_BME280.h>

constexpr unsigned long PRINT_INTERVAL_MS = 1000;
constexpr float MIN_PLAUSIBLE_PRESSURE_HPA = 850.0F;
constexpr float MAX_PLAUSIBLE_PRESSURE_HPA = 1100.0F;
constexpr byte BME_RESET_REGISTER = 0xE0;
constexpr byte BME_RESET_COMMAND = 0xB6;
constexpr byte BME_STATUS_REGISTER = 0xF3;
constexpr byte BME_CTRL_HUM_REGISTER = 0xF2;
constexpr byte BME_CTRL_MEAS_REGISTER = 0xF4;
constexpr byte BME_FORCED_CTRL_HUM = 0x01;
constexpr byte BME_SLEEP_CTRL_MEAS = 0x24;
constexpr byte BME_FORCED_CTRL_MEAS = 0x25;
constexpr byte BME_STATUS_MEASURING = 0x08;
constexpr bool USE_FORCED_MODE = false;
constexpr float FALLBACK_COMPENSATION_TEMP_C = 23.0F;

Adafruit_BME280 bme;
unsigned long lastPrintMs = 0;
byte bmeAddress = 0;

struct BmeCalibration {
  uint16_t digT1;
  int16_t digT2;
  int16_t digT3;
  uint16_t digP1;
  int16_t digP2;
  int16_t digP3;
  int16_t digP4;
  int16_t digP5;
  int16_t digP6;
  int16_t digP7;
  int16_t digP8;
  int16_t digP9;
  uint8_t digH1;
  int16_t digH2;
  uint8_t digH3;
  int16_t digH4;
  int16_t digH5;
  int8_t digH6;
};

struct BmeRaw {
  int32_t pressure;
  int32_t temperature;
  int32_t humidity;
};

void softResetAddress(byte address) {
  Wire.beginTransmission(address);
  Wire.write(BME_RESET_REGISTER);
  Wire.write(BME_RESET_COMMAND);
  Wire.endTransmission();
}

void softResetPossibleBme() {
  softResetAddress(0x76);
  softResetAddress(0x77);
  delay(300);
}

bool beginBme(byte address) {
  if (bme.begin(address, &Wire)) {
    bmeAddress = address;
    if (USE_FORCED_MODE) {
      bme.setSampling(Adafruit_BME280::MODE_SLEEP,
                      Adafruit_BME280::SAMPLING_X1,
                      Adafruit_BME280::SAMPLING_X1,
                      Adafruit_BME280::SAMPLING_X1,
                      Adafruit_BME280::FILTER_OFF,
                      Adafruit_BME280::STANDBY_MS_1000);
    } else {
      bme.setSampling(Adafruit_BME280::MODE_NORMAL,
                      Adafruit_BME280::SAMPLING_X1,
                      Adafruit_BME280::SAMPLING_X1,
                      Adafruit_BME280::SAMPLING_X1,
                      Adafruit_BME280::FILTER_OFF,
                      Adafruit_BME280::STANDBY_MS_1000);
    }
    return true;
  }
  return false;
}

byte readRegister(byte reg) {
  Wire.beginTransmission(bmeAddress);
  Wire.write(reg);
  Wire.endTransmission(false);
  Wire.requestFrom((int)bmeAddress, 1);

  if (Wire.available()) {
    return Wire.read();
  }
  return 0;
}

void writeRegister(byte reg, byte value) {
  Wire.beginTransmission(bmeAddress);
  Wire.write(reg);
  Wire.write(value);
  Wire.endTransmission();
}

bool waitMeasurementReady(unsigned long timeoutMs) {
  const unsigned long startMs = millis();

  while (millis() - startMs < timeoutMs) {
    if ((readRegister(BME_STATUS_REGISTER) & BME_STATUS_MEASURING) == 0) {
      return true;
    }
    delay(2);
  }

  return false;
}

bool triggerForcedMeasurement() {
  writeRegister(BME_CTRL_MEAS_REGISTER, BME_SLEEP_CTRL_MEAS);
  delay(2);
  writeRegister(BME_CTRL_HUM_REGISTER, BME_FORCED_CTRL_HUM);
  writeRegister(BME_CTRL_MEAS_REGISTER, BME_FORCED_CTRL_MEAS);
  delay(50);
  return waitMeasurementReady(250);
}

uint16_t read16(byte reg) {
  const uint16_t msb = readRegister(reg);
  const uint16_t lsb = readRegister(reg + 1);
  return (msb << 8) | lsb;
}

uint16_t read16Le(byte reg) {
  const uint16_t value = read16(reg);
  return (value >> 8) | (value << 8);
}

int16_t readS16Le(byte reg) {
  return (int16_t)read16Le(reg);
}

uint32_t read24(byte reg) {
  const uint32_t msb = readRegister(reg);
  const uint32_t lsb = readRegister(reg + 1);
  const uint32_t xlsb = readRegister(reg + 2);
  return (msb << 16) | (lsb << 8) | xlsb;
}

BmeCalibration readCalibration() {
  BmeCalibration cal;
  const byte h4Msb = readRegister(0xE4);
  const byte h45 = readRegister(0xE5);
  const byte h5Msb = readRegister(0xE6);

  cal.digT1 = read16Le(0x88);
  cal.digT2 = readS16Le(0x8A);
  cal.digT3 = readS16Le(0x8C);
  cal.digP1 = read16Le(0x8E);
  cal.digP2 = readS16Le(0x90);
  cal.digP3 = readS16Le(0x92);
  cal.digP4 = readS16Le(0x94);
  cal.digP5 = readS16Le(0x96);
  cal.digP6 = readS16Le(0x98);
  cal.digP7 = readS16Le(0x9A);
  cal.digP8 = readS16Le(0x9C);
  cal.digP9 = readS16Le(0x9E);
  cal.digH1 = readRegister(0xA1);
  cal.digH2 = readS16Le(0xE1);
  cal.digH3 = readRegister(0xE3);
  cal.digH4 = ((int16_t)((int8_t)h4Msb) << 4) | (h45 & 0x0F);
  cal.digH5 = ((int16_t)((int8_t)h5Msb) << 4) | (h45 >> 4);
  cal.digH6 = (int8_t)readRegister(0xE7);

  return cal;
}

BmeRaw readRaw() {
  BmeRaw raw;
  raw.pressure = (int32_t)(read24(0xF7) >> 4);
  raw.temperature = (int32_t)(read24(0xFA) >> 4);
  raw.humidity = (int32_t)read16(0xFD);
  return raw;
}

bool calibrationLooksSane(const BmeCalibration &cal) {
  return cal.digT1 != 0 && cal.digT1 != 0xFFFF && cal.digP1 != 0 && cal.digP1 != 0xFFFF;
}

float manualTemperatureC(const BmeCalibration &cal, int32_t adcT, int32_t &tFine) {
  int32_t var1 = ((((adcT >> 3) - ((int32_t)cal.digT1 << 1))) * ((int32_t)cal.digT2)) >> 11;
  int32_t var2 = (((((adcT >> 4) - ((int32_t)cal.digT1)) * ((adcT >> 4) - ((int32_t)cal.digT1))) >> 12) * ((int32_t)cal.digT3)) >> 14;
  tFine = var1 + var2;
  const int32_t temperature = (tFine * 5 + 128) >> 8;
  return temperature / 100.0F;
}

float manualPressureHpa(const BmeCalibration &cal, int32_t adcP, int32_t tFine) {
  int64_t var1 = ((int64_t)tFine) - 128000;
  int64_t var2 = var1 * var1 * (int64_t)cal.digP6;
  var2 = var2 + ((var1 * (int64_t)cal.digP5) << 17);
  var2 = var2 + (((int64_t)cal.digP4) << 35);
  var1 = ((var1 * var1 * (int64_t)cal.digP3) >> 8) + ((var1 * (int64_t)cal.digP2) << 12);
  var1 = (((((int64_t)1) << 47) + var1) * (int64_t)cal.digP1) >> 33;

  if (var1 == 0) {
    return NAN;
  }

  int64_t pressure = 1048576 - adcP;
  pressure = (((pressure << 31) - var2) * 3125) / var1;
  var1 = ((int64_t)cal.digP9 * (pressure >> 13) * (pressure >> 13)) >> 25;
  var2 = ((int64_t)cal.digP8 * pressure) >> 19;
  pressure = ((pressure + var1 + var2) >> 8) + (((int64_t)cal.digP7) << 4);
  return pressure / 25600.0F;
}

float manualHumidityPct(const BmeCalibration &cal, int32_t adcH, int32_t tFine) {
  int32_t value = tFine - 76800;
  value = (((((adcH << 14) - (((int32_t)cal.digH4) << 20) - (((int32_t)cal.digH5) * value)) + 16384) >> 15) *
           (((((((value * ((int32_t)cal.digH6)) >> 10) * (((value * ((int32_t)cal.digH3)) >> 11) + 32768)) >> 10) + 2097152) *
             ((int32_t)cal.digH2) + 8192) >> 14));
  value = value - (((((value >> 15) * (value >> 15)) >> 7) * ((int32_t)cal.digH1)) >> 4);

  if (value < 0) {
    value = 0;
  }
  if (value > 419430400) {
    value = 419430400;
  }
  return (value >> 12) / 1024.0F;
}

int32_t tFineFromTemperatureC(float temperatureC) {
  return (int32_t)((temperatureC * 100.0F * 256.0F) / 5.0F);
}

void printFloat1(float value) {
  Serial.print(value, 1);
}

void printHexByte(byte value) {
  if (value < 16) {
    Serial.print('0');
  }
  Serial.print(value, HEX);
}

bool pressurePlausible(float pressureHpa) {
  return pressureHpa >= MIN_PLAUSIBLE_PRESSURE_HPA && pressureHpa <= MAX_PLAUSIBLE_PRESSURE_HPA;
}

void printRawDiagnostic() {
  bool sampleReady = true;
  if (USE_FORCED_MODE) {
    sampleReady = triggerForcedMeasurement();
  } else {
    delay(150);
  }

  const BmeCalibration cal = readCalibration();
  const BmeRaw raw = readRaw();
  int32_t tFine = 0;
  const float manualTempC = manualTemperatureC(cal, raw.temperature, tFine);
  const float manualPressureHpaValue = manualPressureHpa(cal, raw.pressure, tFine);
  const float manualHumidityPctValue = manualHumidityPct(cal, raw.humidity, tFine);
  const int32_t fallbackTFine = tFineFromTemperatureC(FALLBACK_COMPENSATION_TEMP_C);
  const float fallbackPressureHpa = manualPressureHpa(cal, raw.pressure, fallbackTFine);

  Serial.print(F("raw_id=0x"));
  printHexByte(readRegister(0xD0));
  Serial.print(F(" status=0x"));
  printHexByte(readRegister(0xF3));
  Serial.print(F(" ctrl_hum=0x"));
  printHexByte(readRegister(0xF2));
  Serial.print(F(" ctrl_meas=0x"));
  printHexByte(readRegister(0xF4));
  Serial.print(F(" config=0x"));
  printHexByte(readRegister(0xF5));
  Serial.print(F(" sample_mode="));
  Serial.print(USE_FORCED_MODE ? F("forced") : F("normal"));
  Serial.print(F(" ready="));
  Serial.print(sampleReady ? F("yes") : F("no"));
  Serial.println();

  Serial.print(F("cal_T1="));
  Serial.print(cal.digT1);
  Serial.print(F(" cal_T2="));
  Serial.print(cal.digT2);
  Serial.print(F(" cal_T3="));
  Serial.print(cal.digT3);
  Serial.print(F(" cal_P1="));
  Serial.print(cal.digP1);
  Serial.print(F(" cal_sane="));
  Serial.println(calibrationLooksSane(cal) ? F("yes") : F("no"));

  Serial.print(F("raw_adc_P="));
  Serial.print(raw.pressure);
  Serial.print(F(" raw_adc_T="));
  Serial.print(raw.temperature);
  Serial.print(F(" raw_adc_H="));
  Serial.println(raw.humidity);

  Serial.print(F("manual_pressure_hpa="));
  printFloat1(manualPressureHpaValue);
  Serial.print(F(" manual_pressure_ok="));
  Serial.print(pressurePlausible(manualPressureHpaValue) ? F("yes") : F("no"));
  Serial.print(F(" manual_temp_c="));
  printFloat1(manualTempC);
  Serial.print(F(" manual_humidity_pct="));
  printFloat1(manualHumidityPctValue);
  Serial.println();

  Serial.print(F("fallback_temp_c="));
  printFloat1(FALLBACK_COMPENSATION_TEMP_C);
  Serial.print(F(" fallback_pressure_hpa="));
  printFloat1(fallbackPressureHpa);
  Serial.print(F(" fallback_pressure_ok="));
  Serial.print(pressurePlausible(fallbackPressureHpa) ? F("yes") : F("no"));
  Serial.println();
}

void setup() {
  Serial.begin(115200);
  Wire.begin();

  Serial.println(F("BahayShield G2 M11 BME280"));
  Serial.println(F("connect only after voltage safety is accepted"));

  softResetPossibleBme();

  if (!beginBme(0x76) && !beginBme(0x77)) {
    Serial.println(F("bme280_not_found"));
    while (true) {
    }
  }

  Serial.print(F("bme280_addr=0x"));
  printHexByte(bmeAddress);
  Serial.println();
  Serial.print(F("sensor_id=0x"));
  printHexByte(bme.sensorID());
  Serial.println();

  printRawDiagnostic();
}

void loop() {
  const unsigned long now = millis();

  if (now - lastPrintMs >= PRINT_INTERVAL_MS) {
    lastPrintMs = now;
    bool sampleReady = true;
    if (USE_FORCED_MODE) {
      sampleReady = triggerForcedMeasurement();
    }
    const float pressureHpa = bme.readPressure() / 100.0F;
    const float temperatureC = bme.readTemperature();
    const float humidity = bme.readHumidity();
    const float altitudeM = bme.readAltitude(1013.25F);
    const BmeCalibration cal = readCalibration();
    const BmeRaw raw = readRaw();
    const float fallbackPressureHpa = manualPressureHpa(cal, raw.pressure, tFineFromTemperatureC(FALLBACK_COMPENSATION_TEMP_C));

    Serial.print(F("pressure_hpa="));
    printFloat1(pressureHpa);
    Serial.print(F(" pressure_ok="));
    Serial.print(pressurePlausible(pressureHpa) ? F("yes") : F("no"));
    Serial.print(F(" sample_mode="));
    Serial.print(USE_FORCED_MODE ? F("forced") : F("normal"));
    Serial.print(F(" ready="));
    Serial.print(sampleReady ? F("yes") : F("no"));
    Serial.print(F(" temp_c="));
    printFloat1(temperatureC);
    Serial.print(F(" humidity_pct="));
    printFloat1(humidity);
    Serial.print(F(" fallback_pressure_hpa="));
    printFloat1(fallbackPressureHpa);
    Serial.print(F(" fallback_pressure_ok="));
    Serial.print(pressurePlausible(fallbackPressureHpa) ? F("yes") : F("no"));
    Serial.print(F(" altitude_m_from_1013="));
    printFloat1(altitudeM);
    Serial.println();
  }
}

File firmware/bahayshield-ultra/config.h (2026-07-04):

#ifndef BAHAYSHIELD_CONFIG_H
#define BAHAYSHIELD_CONFIG_H

#include <Arduino.h>

constexpr uint32_t SERIAL_BAUD = 115200;

constexpr uint8_t LCD_ADDR_PRIMARY = 0x27;
constexpr uint8_t LCD_ADDR_FALLBACK = 0x3F;
constexpr uint8_t PCF8574_ADDR = 0x20;
constexpr uint8_t DS3231_ADDR = 0x68;
constexpr uint8_t AT24C32_ADDR = 0x57;
constexpr uint8_t BME280_ADDR = 0x76;
constexpr uint8_t BME280_EXPECTED_ID = 0x60;

constexpr uint32_t BUTTON_INTERVAL_MS = 25;
constexpr uint32_t BUTTON_DEBOUNCE_MS = 80;
constexpr uint8_t BUTTON_ADC_SAMPLES = 12;
constexpr uint32_t KEYPAD_INTERVAL_MS = 35;
constexpr uint32_t PRESSURE_INTERVAL_MS = 1000;
constexpr uint8_t PRESSURE_ADC_SAMPLES = 16;
constexpr int16_t PRESSURE_MAX_STEP_TENTH_HPA = 8;
constexpr uint32_t BME_INTERVAL_MS = 2000;
constexpr uint32_t RTC_INTERVAL_MS = 1000;
constexpr uint32_t TRI_INTERVAL_MS = 100;
constexpr uint32_t LCD_INTERVAL_MS = 1000;
constexpr uint32_t SERIAL_INTERVAL_MS = 1000;
constexpr uint32_t ULTRASONIC_INTERVAL_MS = 100;
constexpr uint32_t ULTRASONIC_TIMEOUT_US = 30000;
constexpr uint32_t FAULT_TIMEOUT_MS = 2500;

constexpr int16_t WATER_REFERENCE_MM = 120;
constexpr int16_t WATER_MAX_MM = 70;
constexpr int16_t WATER_ANKLE_MM = 15;
constexpr int16_t WATER_KNEE_MM = 30;
constexpr int16_t WATER_WAIST_MM = 55;
constexpr uint32_t POWER_CUT_CONFIRM_MS = 30000;
constexpr uint32_t SAFE_CLEAR_MS = 30000;

constexpr int16_t PRESSURE_MIN_TENTH_HPA = 9850;
constexpr int16_t PRESSURE_MAX_TENTH_HPA = 10130;
constexpr int16_t PRESSURE_BASELINE_TENTH_HPA = 10130;
constexpr int16_t SEVERE_SLOPE_TENTH_HPA_PER_MIN = 60;
constexpr int16_t SEVERE_DROP_TENTH_HPA = 280;

constexpr uint8_t TRI_WATCH_ENTER = 40;
constexpr uint8_t TRI_WATCH_EXIT = 35;
constexpr uint8_t TRI_WARNING1_ENTER = 65;
constexpr uint8_t TRI_WARNING1_EXIT = 60;
constexpr uint8_t TRI_WARNING2_ENTER = 85;
constexpr uint8_t TRI_EVACUATE_ENTER = 95;

constexpr uint16_t BUTTON_BLUE_MIN = 45;
constexpr uint16_t BUTTON_BLUE_MAX = 75;
constexpr uint16_t BUTTON_NONE_MIN = 80;
constexpr uint16_t BUTTON_NONE_MAX = 94;
constexpr uint16_t BUTTON_GREEN_MIN = 95;
constexpr uint16_t BUTTON_GREEN_MAX = 105;
constexpr uint16_t BUTTON_YELLOW_MIN = 106;
constexpr uint16_t BUTTON_YELLOW_MAX = 130;

constexpr uint16_t BUZZER_ACTION_MS = 100;
constexpr uint16_t BUZZER_WATCH_ON_MS = 80;
constexpr uint16_t BUZZER_WATCH_PERIOD_MS = 4000;
constexpr uint16_t BUZZER_WARNING1_ON_MS = 100;
constexpr uint16_t BUZZER_WARNING1_PERIOD_MS = 1800;
constexpr uint16_t BUZZER_WARNING2_ON_MS = 150;
constexpr uint16_t BUZZER_WARNING2_PERIOD_MS = 800;
constexpr uint16_t BUZZER_EVAC_ON_MS = 250;
constexpr uint16_t BUZZER_EVAC_PERIOD_MS = 500;

#endif

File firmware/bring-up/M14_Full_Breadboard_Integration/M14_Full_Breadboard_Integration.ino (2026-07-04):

#include <Wire.h>
#include <Adafruit_BME280.h>

constexpr byte PIN_US_TRIG = 2;
constexpr byte PIN_US_ECHO = 3;
constexpr byte PIN_RELAY1 = 4;
constexpr byte PIN_RELAY2 = 5;
constexpr byte PIN_LED_G1 = 6;
constexpr byte PIN_LED_G2 = 7;
constexpr byte PIN_LED_Y = 8;
constexpr byte PIN_LED_O = 9;
constexpr byte PIN_LED_R = 10;
constexpr byte PIN_LED_ALERT = 11;
constexpr byte PIN_BUZZER = 12;
constexpr byte PIN_PRESSURE = A0;
constexpr byte PIN_BUTTONS = A1;

constexpr byte RELAY_ACTIVE = LOW;
constexpr byte RELAY_INACTIVE = HIGH;

constexpr byte LCD_ADDR_PRIMARY = 0x27;
constexpr byte LCD_ADDR_FALLBACK = 0x3F;
constexpr byte PCF8574_ADDR = 0x20;
constexpr byte DS3231_ADDR = 0x68;
constexpr byte AT24C32_ADDR = 0x57;

constexpr byte LCD_BACKLIGHT = 0x08;
constexpr byte LCD_ENABLE = 0x04;
constexpr byte LCD_RS = 0x01;

constexpr unsigned long STATUS_INTERVAL_MS = 1000;
constexpr unsigned long LCD_INTERVAL_MS = 500;
constexpr unsigned long BUTTON_INTERVAL_MS = 40;
constexpr unsigned long KEYPAD_INTERVAL_MS = 35;
constexpr unsigned long BME_INTERVAL_MS = 2000;
constexpr unsigned long RTC_INTERVAL_MS = 1000;
constexpr unsigned long ULTRASONIC_INTERVAL_MS = 250;
constexpr unsigned long ULTRASONIC_TIMEOUT_US = 30000;
constexpr unsigned long BUZZER_MS = 120;

const byte LED_PINS[] = {PIN_LED_G1, PIN_LED_G2, PIN_LED_Y, PIN_LED_O, PIN_LED_R};

const char KEYMAP[4][4] = {
  {'1', '4', '7', '*'},
  {'2', '5', '8', '0'},
  {'3', '6', '9', '#'},
  {'A', 'B', 'C', 'D'}
};

enum ButtonId : byte {
  BTN_NONE,
  BTN_YELLOW_CUT,
  BTN_BLUE_VIEW,
  BTN_GREEN_ACK,
  BTN_AMBIGUOUS
};

enum EchoState : byte {
  ECHO_IDLE,
  ECHO_WAIT_RISE,
  ECHO_WAIT_FALL
};

Adafruit_BME280 bme;

byte lcdAddress = 0;
byte lcdPage = 0;
byte bmeAddress = 0;
bool lcdOk = false;
bool keypadOk = false;
bool rtcOk = false;
bool eepromOk = false;
bool bmeOk = false;
bool relayCut = false;
bool ultrasonicValid = false;

ButtonId stableButton = BTN_NONE;
ButtonId pendingButton = BTN_NONE;
char lastKey = 0;

EchoState echoState = ECHO_IDLE;

unsigned long lastStatusMs = 0;
unsigned long lastLcdMs = 0;
unsigned long lastButtonMs = 0;
unsigned long lastKeypadMs = 0;
unsigned long lastBmeMs = 0;
unsigned long lastRtcMs = 0;
unsigned long lastUltrasonicMs = 0;
unsigned long buttonPendingSinceMs = 0;
unsigned long buzzerUntilMs = 0;
unsigned long triggerStartUs = 0;
unsigned long echoRiseUs = 0;
unsigned long ultrasonicEchoUs = 0;

int pressureTenthHpa = 0;
int waterMm = 0;
int ultrasonicDistanceMm = -1;
int bmePressureTenthHpa = 0;
int bmeTempTenthC = 0;
int bmeHumidityTenthPct = 0;
byte rtcHours = 0;
byte rtcMinutes = 0;
byte rtcSeconds = 0;

bool i2cPresent(byte address) {
  Wire.beginTransmission(address);
  return Wire.endTransmission() == 0;
}

void printHexByte(byte value) {
  if (value < 16) {
    Serial.print('0');
  }
  Serial.print(value, HEX);
}

byte bcdToDec(byte value) {
  return ((value >> 4) * 10) + (value & 0x0F);
}

void printTenth(int value) {
  Serial.print(value / 10);
  Serial.print('.');
  Serial.print(abs(value % 10));
}

void lcdWriteExpander(byte value) {
  if (!lcdOk) {
    return;
  }
  Wire.beginTransmission(lcdAddress);
  Wire.write(value | LCD_BACKLIGHT);
  if (Wire.endTransmission() != 0) {
    lcdOk = false;
  }
}

void lcdPulse(byte value) {
  lcdWriteExpander(value | LCD_ENABLE);
  delayMicroseconds(1);
  lcdWriteExpander(value & ~LCD_ENABLE);
  delayMicroseconds(50);
}

void lcdWrite4(byte value, byte mode) {
  lcdPulse((value & 0xF0) | mode);
}

void lcdWrite(byte value, byte mode) {
  lcdWrite4(value & 0xF0, mode);
  lcdWrite4((value << 4) & 0xF0, mode);
}

void lcdCommand(byte value) {
  lcdWrite(value, 0);
  if (value == 0x01 || value == 0x02) {
    delay(2);
  }
}

void lcdData(byte value) {
  lcdWrite(value, LCD_RS);
}

void lcdSetCursor(byte col, byte row) {
  static const byte offsets[] = {0x00, 0x40, 0x14, 0x54};
  lcdCommand(0x80 | (col + offsets[row]));
}

void lcdPrintFixed(const char *text) {
  byte count = 0;
  while (*text && count < 20) {
    lcdData(*text++);
    ++count;
  }
  while (count < 20) {
    lcdData(' ');
    ++count;
  }
}

void lcdInit() {
  delay(50);
  lcdWrite4(0x30, 0);
  delay(5);
  lcdWrite4(0x30, 0);
  delayMicroseconds(150);
  lcdWrite4(0x30, 0);
  lcdWrite4(0x20, 0);
  lcdCommand(0x28);
  lcdCommand(0x08);
  lcdCommand(0x01);
  lcdCommand(0x06);
  lcdCommand(0x0C);
}

void pcfWrite(byte value) {
  Wire.beginTransmission(PCF8574_ADDR);
  Wire.write(value);
  if (Wire.endTransmission() != 0) {
    keypadOk = false;
  }
}

byte pcfRead() {
  Wire.requestFrom(PCF8574_ADDR, byte(1));
  if (Wire.available()) {
    return Wire.read();
  }
  keypadOk = false;
  return 0xFF;
}

char scanKeypad() {
  if (!keypadOk) {
    return 0;
  }
  for (byte row = 0; row < 4; ++row) {
    byte output = 0xFF;
    output &= ~(1 << row);
    pcfWrite(output);
    delayMicroseconds(80);
    const byte input = pcfRead();
    for (byte col = 0; col < 4; ++col) {
      const byte bitIndex = col + 4;
      if ((input & (1 << bitIndex)) == 0) {
        pcfWrite(0xFF);
        return KEYMAP[row][col];
      }
    }
  }
  pcfWrite(0xFF);
  return 0;
}

ButtonId decodeButton(int adc) {
  if (adc >= 900 && adc <= 1000) {
    return BTN_YELLOW_CUT;
  }
  if (adc >= 780 && adc <= 890) {
    return BTN_BLUE_VIEW;
  }
  if (adc >= 630 && adc <= 760) {
    return BTN_GREEN_ACK;
  }
  if (adc >= 0 && adc <= 80) {
    return BTN_NONE;
  }
  return BTN_AMBIGUOUS;
}

const __FlashStringHelper *buttonName(ButtonId button) {
  switch (button) {
    case BTN_YELLOW_CUT:
      return F("YELLOW_CUT");
    case BTN_BLUE_VIEW:
      return F("BLUE_VIEW");
    case BTN_GREEN_ACK:
      return F("GREEN_ACK");
    case BTN_AMBIGUOUS:
      return F("AMBIGUOUS");
    default:
      return F("NONE");
  }
}

void setRelayCut(bool cut) {
  relayCut = cut;
  digitalWrite(PIN_RELAY1, relayCut ? RELAY_ACTIVE : RELAY_INACTIVE);
  digitalWrite(PIN_RELAY2, RELAY_INACTIVE);
}

void startBeep(unsigned long now) {
  digitalWrite(PIN_BUZZER, HIGH);
  buzzerUntilMs = now + BUZZER_MS;
}

void updateBuzzer(unsigned long now) {
  if (buzzerUntilMs != 0 && now - buzzerUntilMs < 0x80000000UL) {
    digitalWrite(PIN_BUZZER, LOW);
    buzzerUntilMs = 0;
  }
}

void updatePressure() {
  const int adc = analogRead(PIN_PRESSURE);
  pressureTenthHpa = map(adc, 0, 1023, 9850, 10130);
}

void updateIndicators() {
  byte level = 0;
  if (ultrasonicValid) {
    if (waterMm >= 55) {
      level = 5;
    } else if (waterMm >= 45) {
      level = 4;
    } else if (waterMm >= 30) {
      level = 3;
    } else if (waterMm >= 15) {
      level = 2;
    } else if (waterMm > 0) {
      level = 1;
    }
  }

  for (byte i = 0; i < sizeof(LED_PINS); ++i) {
    digitalWrite(LED_PINS[i], i < level ? HIGH : LOW);
  }
  digitalWrite(PIN_LED_ALERT, (ultrasonicValid && waterMm >= 55) || relayCut ? HIGH : LOW);
}
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

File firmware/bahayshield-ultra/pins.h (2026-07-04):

#ifndef BAHAYSHIELD_PINS_H
#define BAHAYSHIELD_PINS_H

#include <Arduino.h>

constexpr uint8_t PIN_US_TRIG = 2;
constexpr uint8_t PIN_US_ECHO = 3;
constexpr uint8_t PIN_RELAY1 = 4;
constexpr uint8_t PIN_RELAY2 = 5;
constexpr uint8_t PIN_LED_G1 = 6;
constexpr uint8_t PIN_LED_G2 = 7;
constexpr uint8_t PIN_LED_Y = 8;
constexpr uint8_t PIN_LED_O = 9;
constexpr uint8_t PIN_LED_R = 10;
constexpr uint8_t PIN_LED_ALERT = 11;
constexpr uint8_t PIN_BUZZER = 12;
constexpr uint8_t PIN_PRESSURE = A0;
constexpr uint8_t PIN_BUTTONS = A1;

constexpr uint8_t RELAY_ACTIVE_LEVEL = LOW;
constexpr uint8_t RELAY_INACTIVE_LEVEL = HIGH;

#endif

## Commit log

2026-07-04 feat: add enclosure STL and OpenSCAD sources
    [bahayshield-base-tray.stl, bahayshield-enclosure.scad, bme280-vent-cage.stl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]
2026-07-04 feat: add curated bring-up driver suite
2026-07-05 feat: add Rev A KiCad project and Prototype-1 archive
    [BahayShield-ULTRA-RevA-Manual.kicad_pcb, BahayShield-ULTRA-RevA-Manual.kicad_sch, bahayshield_ultra_prototype_1.kicad_pcb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]
2026-07-15 docs: product README, pinout, power tree, and demo notes
2026-07-15 docs: polish portfolio README, gallery, and board naming
